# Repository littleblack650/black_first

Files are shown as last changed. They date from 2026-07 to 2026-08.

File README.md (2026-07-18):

# -
小鱼干 是一款全磁吸、模块化的开源桌宠机器人。它集成了语音识别、姿态感知、表情动画与舵机动作，支持二次开发，适合机器人爱好者、创客和学生入门嵌入式与机器人技术。/XiaoYuGan is an open‑source, fully magnetic modular desktop pet robot. It combines offline voice recognition, motion sensing, expressive animations, and servo movements, making it an ideal learning platform for embedded systems and robotics.

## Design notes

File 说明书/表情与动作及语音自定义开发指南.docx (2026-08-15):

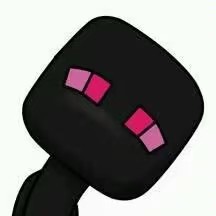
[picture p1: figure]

小鱼干桌宠机器人 · 表情与动作及语音

自定义开发指南

作者：生活中的小黑

本文档旨在说明如何为机器人新增一个表情（单帧或多帧动画），并为该表情编写对应的舵机动作序列，使其在表情播放时同步执行并自定义语音指令。

一、总体流程概览

阶段一：添加新表情

1. 定义表情类型（face.h 中增加枚举）
2. 生成并烧录图片（取模 → 上传到 Flash，记录地址）
3. 定义动画序列（face.c 中创建帧数组，单帧可跳过）
4. 配置表情参数（face.c 的配置表中注册表情）

→ 成果：OLED 能显示该表情

阶段二：编写舵机动作

1. 实现非阻塞动作函数（pwm.c 中用 ServoSequenceCommand 或 Servo_Set_NonBlocking 编写）
2. 在 system_manager.c 的 ExpressionWithServo 中绑定（表情出现时自动触发动作）

→ 成果：表情播放时舵机同步动作

阶段三：绑定语音指令

1. 定义指令编号（usart.h 枚举中添加）
2. 映射到表情（face.c 的 VoiceCommand_To_FaceType 中添加映射）
3. 配置语音模块（SU-03T 工具中新增词条，返回值与编号一致）
4. 执行业务逻辑（system_manager.c 的 VoiceCommandHandler 中添加处理）

→ 成果：说出口令机器人响应

阶段四：随机表情配置（可选）

在 random.c 的 default_probability_table 中添加概率条目

→ 成果：该表情会在空闲时随机自动出现

阶段五：测试验证

1. 单帧测试（用 W25Q64_ReadData 读取指定地址并显示）
2. 语音触发测试
3. 随机触发测试

→ 成果：功能稳定，可投入使用

二、详细步骤

为便于理解，将整个流程划分为四个独立阶段：

1. 添加新表情（准备图片→配置代码）
2. 关联动作（编写舵机动作→绑定到表情）
3. 绑定语音指令（定义指令→映射→处理）
4. 随机显示配置（设置概率表）

以下按阶段逐步说明，每个阶段只列出必须修改的文件和关键代码。

阶段一：添加新表情

1.1 定义表情类型（face.h）

在 FaceType 枚举中添加新成员，放在 FACE_COUNT 之前。

1.2 准备图片数据并烧录(具体操作可以搜索我的B站和抖音教程)

- 单帧：使用 image2cpp 在线工具将 128×64 图片转为数组。
- 多帧：使用“小黑的视频抽帧工具.exe”提取帧序列。
- 上传：使用“小黑的表情上传工具.exe”通过串口烧录到 W25Q64。
- 记录地址：工具会返回每帧的起始地址（如 0x000000、0x001000）。

接线图：USB转TTL模块与开发板连接方式如下。
模块TXD → 开发板RXD（PA10），模块RXD → 开发板TXD（PA9），共地。

1.3 定义动画序列（face.c，仅多帧）

创建 AnimationFrame 数组，填入地址和延时：

1.4 配置表情参数（face.c）

在 default_face_configs 中添加配置项，注意单帧与多帧的区别：

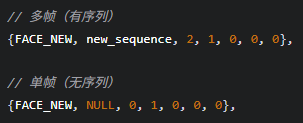
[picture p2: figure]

- sequence：序列指针（多帧填数组名，单帧填 NULL）
- sequence_length：帧数（单帧填 0）
- loop_count：循环次数（0 为无限循环）
- 最后两个 0 为预延迟（一般不用），has_special_behavior 通常为 0

1.5 （仅单帧）设置显示时长（face.c）

在 single_frame_times 中添加：

阶段二：关联动作

2.1 编写舵机动作函数（pwm.c）

必须非阻塞，推荐使用序列命令：

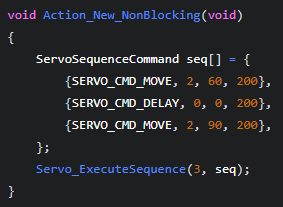
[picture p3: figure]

2.2 关联到表情（system_manager.c）

在 ExpressionWithServo 函数的 switch(currentFace) 中添加：

这样表情出现时自动执行对应动作。

提示：若动作需要由语音单独触发，还需在 VoiceCommandHandler 中添加（见阶段三）。

阶段三：绑定语音指令

3.1 定义指令编号（usart.h）

在 VoiceCommand 枚举中添加新值（推荐 0x30 起）：

3.2 映射到表情（face.c）

在 VoiceCommand_To_FaceType 中添加：

3.3 执行业务逻辑（system_manager.c）

在 VoiceCommandHandler 的 switch (face_type) 中添加：

或者，若动作与表情关联已在阶段二完成，则此处只需触发表情：

3.4 配置语音模块（SU-03T工具）

- 新增词条（如“新指令”），返回值设为 0x30（与3.1一致）。
- 生成固件并烧录到语音模块。

阶段四：随机显示配置

在 random.c 的 default_probability_table 中增加条目：

- 概率值总和不超过100。
- 间隔控制该表情连续出现的频率。

三、注意事项（摘要）

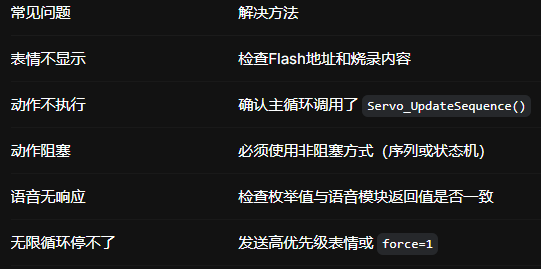
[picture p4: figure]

资源限制：g_sequence 数组大小为20（pwm.c中），若动作命令数超出，请修改数组大小或拆分执行。

通过以上四个阶段，您可以快速为“小鱼干”添加新表情、动作和语音指令，并实现随机展示。更多细节请参考视频教程（B站/抖音：生活中的小黑）。

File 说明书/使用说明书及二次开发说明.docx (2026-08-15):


小鱼干桌宠机器人

使用说明书 & 二次开发指南

感谢您选择“小鱼干”——一款全磁吸、模块化、可编程的智能桌宠机器人。本产品由作者独立开发并生产，所有电路均为模块化设计，无需自行焊接 PCB，方便维修与二次开发。请仔细阅读本手册，让您的小鱼干更快融入您的桌面生活。

一、产品概述

- 产品名称：小鱼干智能桌宠机器人
- 主控：STM32F103C8T6
- 存储器：W25Q64（8MB Flash，存储表情动画）
- 语音模块：SU-03T（支持离线语音指令）
- 姿态传感器：MPU6050（六轴，用于晃动、躺倒检测）
- 显示：1.3 寸 OLED（128×64，黑白）
- 舵机：MG90S ×2（控制头部点头、摇头）
- 电源管理：TP4056 充电 + DC-DC 5V 升压模块
- 触摸传感器：TTP223（电容式，位于头顶）
- 供电：3.7V 锂电池 + Type-C 充电底座

结构特点

- 全磁吸无螺丝设计：外壳采用 3D 打印，各部件通过磁吸固定，无需工具即可拆卸，方便维修与改装。
- 模块化电路：所有电子模块通过杜邦线或排针连接，无需定制 PCB，降低 DIY 门槛。
- 磁吸扩展接口：头部、手臂预留磁吸点，可更换装饰手套、头戴挂件（官方提供多种款式，也支持自制）。

二、包装清单

序号 | 名称 | 数量 | 备注
1 | 小鱼干机器人主体（含电池） | 1 | 默认装配完成
2 | 磁吸充电底座 | 1 | 含 Type-C 母座
3 | 磁吸手套（左右手） | 1 对 | 默认赠送“小鱼干”主题款
4 | 磁吸头戴装饰 | 1 个 | 默认小鱼鳍造型
5 | USB Type-C 数据线 | 1 | 充电/数据传输
6 | 使用说明书 & 二次开发指南 | 1 本 | 电子版见自媒体发布链接

额外装饰配件（如猫耳、蝴蝶结、节日限定款）请关注作者动态。

三、使用说明

3.1 首次使用

1. 充电：将充电底座的 Type-C 口连接到任意 5V USB 电源（手机充电器、电脑 USB、充电宝均可）。充电时底座指示灯亮红，充满转绿。
2. 放置机器人：将小鱼干的底部磁吸触点对准底座凹槽，轻轻放下，听到“咔哒”一声即吸附到位。
3. 开机：机器人左侧为电源开关，拨到“ON”位置，屏幕亮起，播放开机动画。
4. 语音唤醒：直接说出指令词（见附录），机器人会做出表情和动作。

提示：出厂时电池可能为虚电，建议先充电 1 小时再使用。

3.2 充电注意事项

- 边充边用：支持充电时正常使用，不影响语音、表情和舵机动作。
- 充电兼容性：任何 Type-C 手机充电器（5V/1A 及以上）、电脑 USB 口均可。不要求特定充电器。
- 充电状态指示：
  - 底座红灯常亮：充电中
  - 底座蓝灯常亮：充满或未放置机器人
  - 底座灯灭：电源未接通

3.3 电源开关与复位

位置 | 功能
左侧拨动开关 | ON：开机；OFF：关机
右侧 MicroUSB 接口 | SWD 烧录/调试口（供开发者使用）
复位方式 | 若屏幕显示异常，重启即可恢复。

3.4 语音指令映射表

指令编号 | 语音关键词 | 触发表情 | 动作
0x01 | 小鱼干 | RESPOND1 | 点头响应
0x02 | 你好 BT | BT | 无
0x03 | 揍你 | ANGRY1 | 摇头+拒绝
0x04 | 笑一个 | SMILE | 微笑+点头
0x05~0x0B | 音量调节 | RESPOND1 | 仅反馈（无动作）
0x0C | 唱首歌 | KEBISING | 唱歌动画+跳舞
0x0D | 我爱你 | LOVE | 爱心表情+四周看
0x0E | 往上看 | UP | 抬头
0x0F/0x11/0x12 | 狠一点/干他 | ANGRY2/3 | 摆头
0x13 | 哭一个 | CRY | 低头+哭泣动画
0x14 | 伤心 | SAD | 低头+悲伤动画
0x16 | 我帅吗 | DOUBT | 疑惑表情+歪头
0x17 | 吃饭 | EAT | 咀嚼动画+低头
0x18 | 呕吐 | VOMIT | 呕吐动画+挣扎
0x19 | 生气 | ANGRY | 常规生气
0x1A | 往下看 | DOWN | 低头
0x1B | 往左看 | LEFT | 左转头
0x1C | 往右看 | RIGHT | 右转头
0x1D | 给大家拜个年 | BAINIAN | 无
0x1E | 睡觉吧 | SLEEP | 睡眠动画+定格
0x1F | 起床啦 | WAKE | 唤醒动画+抬头
0x20 | 老大 | KEBI | 敬礼动作
0x21 | 老大我想你了 | KEBISING | 唱歌
0x22 | 立正 | RESPOND3 | 挺胸+严肃表情
0x23 | 放个烟花 | DANCE | 点头+烟花动画
0x24 | 曼波 | 无 | 无
0x25 | 真菜 | 无 | 无
0x26 | 真棒 | 无 | 无

3.5 语音及表情烧录引脚说明

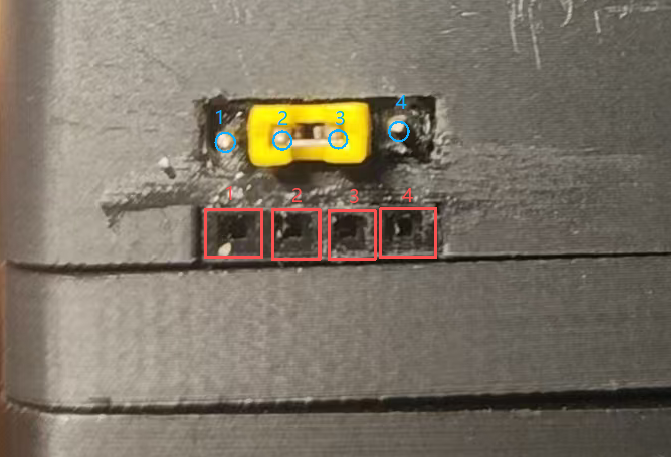
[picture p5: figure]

1. 连接上方4号引脚

2. 连接开发板5v引脚

3. 连接su-03t语音模块的5v引脚

4. 连接下方的1号接口，负责提供5v供电

1. 连接上方4号接口，负责提供5v供电

2. 连接su-03t语音模块的B7/TX引脚和开发板B7/RX引脚

3. 连接su-03t语音模块的B6/RX引脚和开发板B6/TX引脚

4. 连接su-03t语音模块的GND引脚和开发板GND引脚

3.6 语音及表情烧录操作方法

表情烧录：跳线帽连接1号和2号引脚（仅给开发板供电）

且TTL模块的Tx连接下方的2号引脚，Rx连接下方的3号引脚

语音烧录：跳线帽连接3号和4号引脚（仅给语音模块供电）

且TTL模块的Tx连接下方的3号引脚，Rx连接下方的2号引脚

烧录完成后：跳线帽连接2号和3号引脚（开发板给语音模块供电）

四、常见问题

Q：为什么内部走线看起来很乱？
A：为方便模块化更换和维修，所有模块均通过杜邦线连接，未定制 PCB。这可能对部分传感器产生轻微电磁干扰。在插电使用时（电量充足时）干扰最小，建议养成插电习惯。

Q：屏幕偶尔会乱码，怎么办？
A：断电重启即可。此问题通常由静电或电机启动时的大电流瞬时干扰引起，不影响长期可靠性。

Q：电池能续航多久？
A：满电连续使用约 1小时（视表情和动作频率），插电使用可以续航时间无限制。若长时间插电使用，建议偶尔断开电源让电池进行一次完整充放电，以延长寿命。

Q：能自己写新的表情和动作吗？
A：完全可以。我们提供完整的源码、取模工具、上传工具和教程，请参考“二次开发说明”章节。

Q：底座上的两侧触点怎么用？
A：它们是留给高级玩家连接移动底盘、扩展传感器等外部模块的。您可以制作带 MCU 的扩展底座，通过串口或 GPIO 与小鱼干主控通信。

五、支持与社区

- 技术文档与源码：访问作者GitHub仓库或关注作者抖音、哔哩哔哩等自媒体账号在相关视频简介中获取或粉丝交流群中获取
- 视频教程：抖音、哔哩哔哩搜索 “生活中的小黑”，观看表情制作、代码修改、外壳改装等系列视频。
- 问题反馈：可在视频评论区留言或私信，作者会尽量解答。
- 二次开发作品分享：欢迎在话题 #小鱼干改装 下晒出您的创意。

小鱼干桌宠机器人 —— 不仅是桌面萌物，更是您进入嵌入式与机器人世界的起点。
祝您玩得开心，改装出独一无二的小鱼干！

版本：V2.0
发布日期：2026 年 5月
作者：生活中的小黑

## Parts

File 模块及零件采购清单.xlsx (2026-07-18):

物料表
名称 | 数量
stm32f103c8t6最小系统开发板 | 1
st-link仿真器（烧录程序用） | 1
USB转TTL模块（烧录表情和语音用） | 1
su-03t语音模块 | 1
3.7v转5v迷你DC升压模块 | 1
6.3v2200uF电解电容10x12mm | 1
TP4056充电板 | 1
TTP223触摸模块 | 1
彩色排线 | 1
AMS1117-3.3v | 1
圆柱磁铁直径4mm厚度1.65mm | 100
6022P电容麦 | 1
SS12F15VG6拨动开关2档3脚 | 1
PogoPin弹簧针连接器触点1.5x3mm | 8
SMBJ5.0A TVS管 | 1
0402，0.1uF，104电容 | 1
MG90S铁齿180度舵机 | 2
502030，3.7v锂电池 | 1
1.25-2P端子4欧2W3525腔体扬声器 | 1
W25Q64 | 1
MPU6050 | 1
4P单排母直针 | 1
4P排针 | 1
跳线帽 | 1
1.3寸4脚蓝色OLED | 1
3D打印外壳 | 1

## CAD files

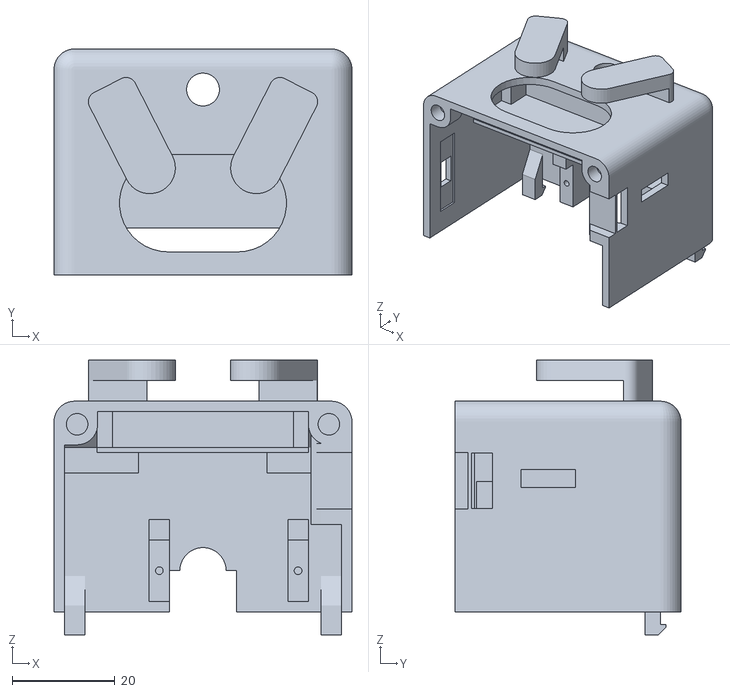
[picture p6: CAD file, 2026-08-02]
外壳打印文件/身体.STL
58.0 x 44.0 x 53.5

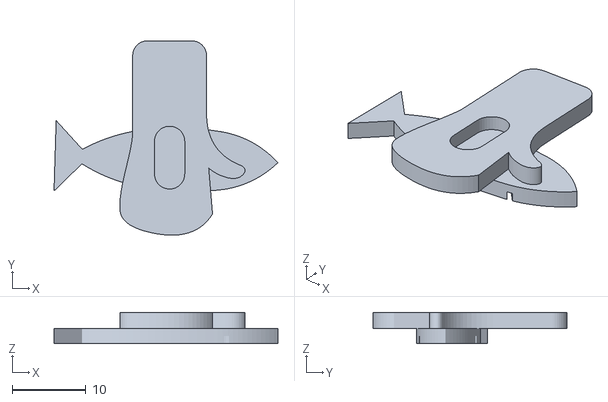
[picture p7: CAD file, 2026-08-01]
外壳打印文件/兔手套.STL
30.3 x 26.3 x 4.20

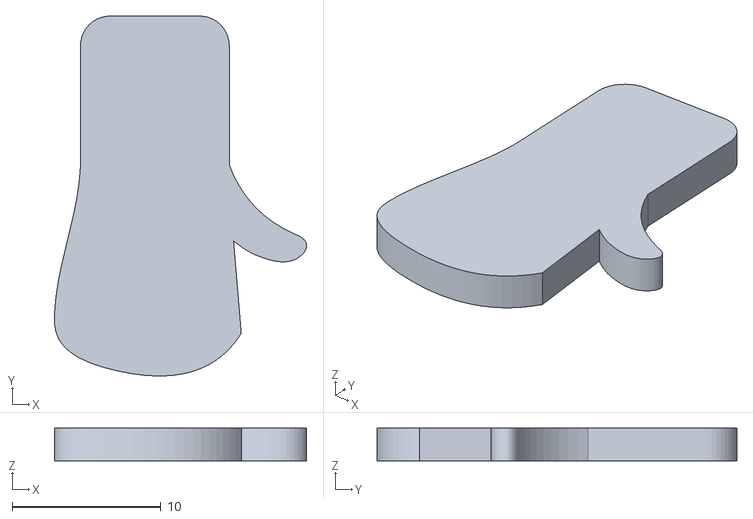
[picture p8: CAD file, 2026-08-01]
外壳打印文件/兔手套右.STL
16.9 x 24.2 x 2.20

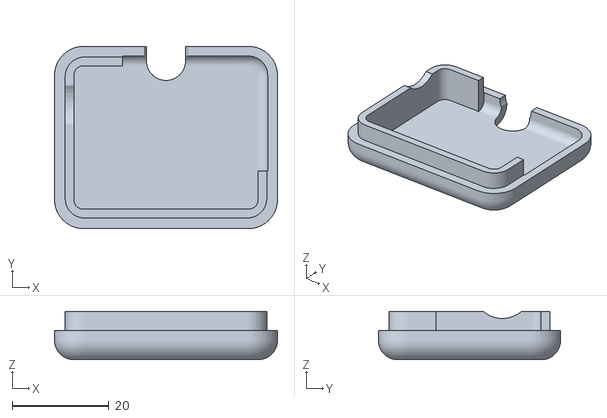
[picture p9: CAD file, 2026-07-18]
外壳打印文件/后脑勺0.2组装公差版本.STL
46.0 x 37.6 x 10.0

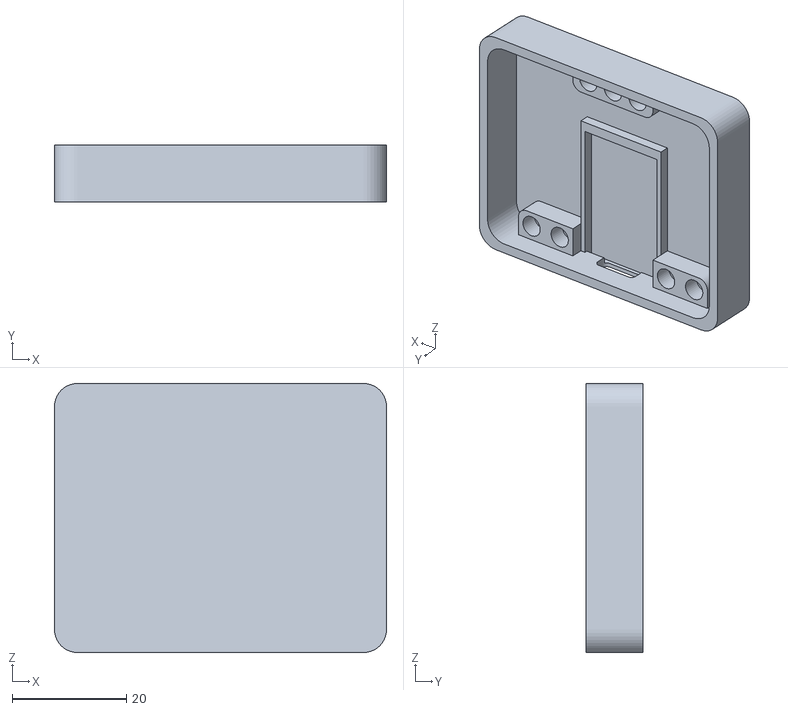
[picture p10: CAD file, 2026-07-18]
外壳打印文件/充电底座下盖.STL
58.0 x 10.0 x 47.0

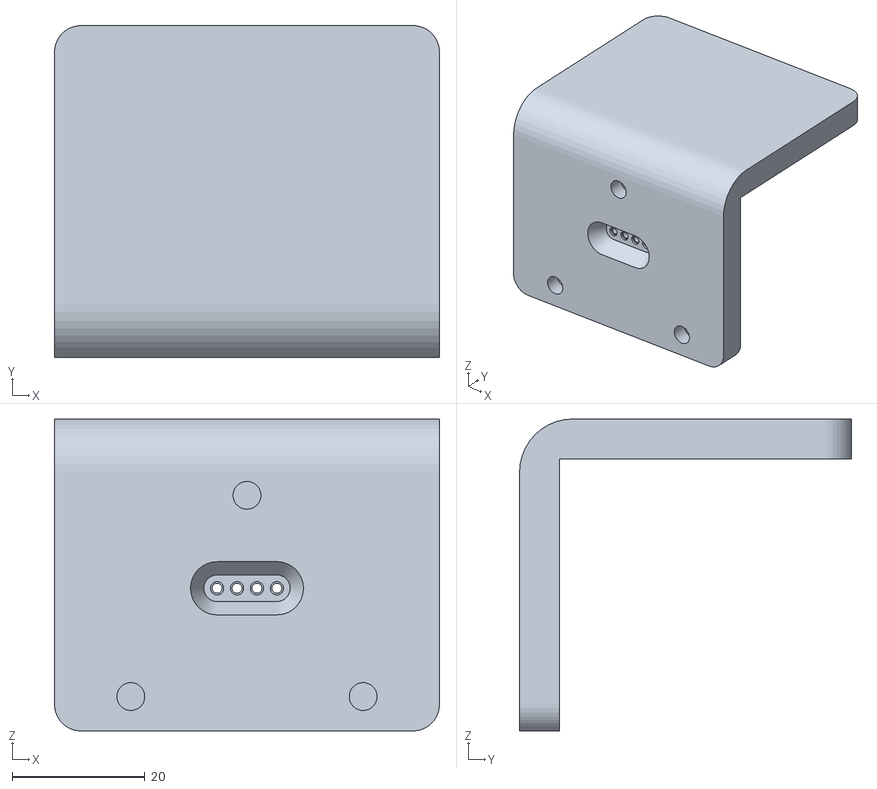
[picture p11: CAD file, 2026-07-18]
外壳打印文件/底盖.STL
58.0 x 50.0 x 47.0

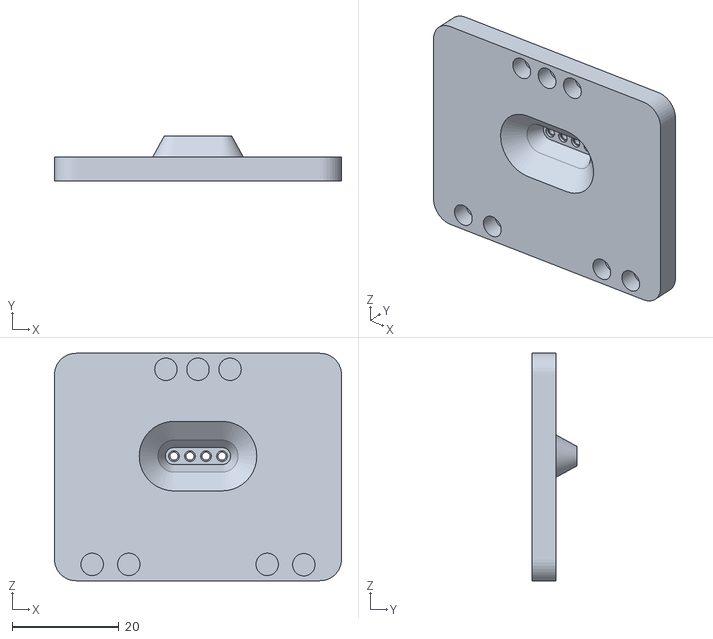
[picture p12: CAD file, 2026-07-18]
外壳打印文件/充电底座上盖.STL
53.7 x 8.50 x 42.6

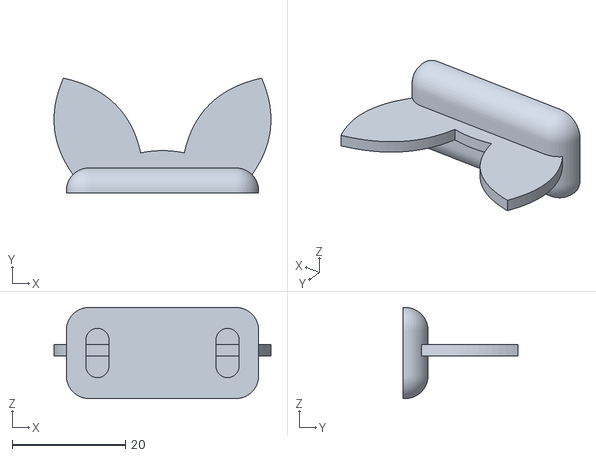
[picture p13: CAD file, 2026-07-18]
外壳打印文件/猫耳朵.STL
38.4 x 20.3 x 16.1

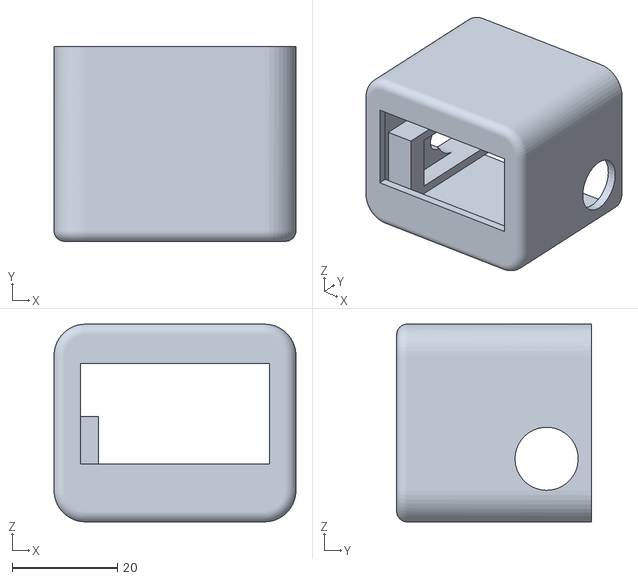
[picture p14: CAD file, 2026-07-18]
外壳打印文件/头部.STL
46.0 x 37.0 x 37.6

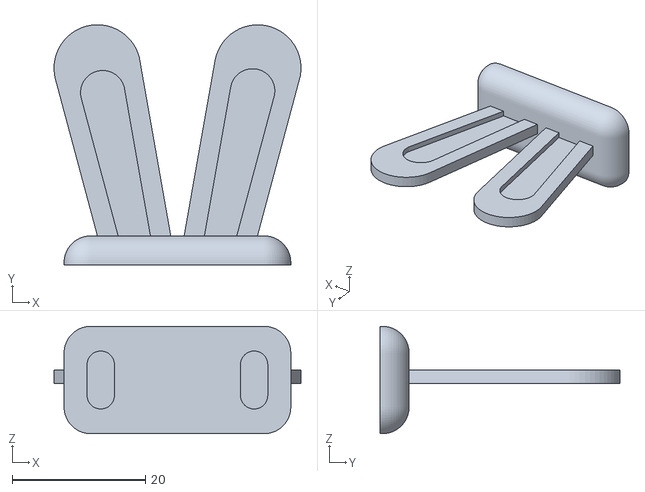
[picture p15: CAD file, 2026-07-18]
外壳打印文件/兔耳朵.STL
37.0 x 36.1 x 16.1

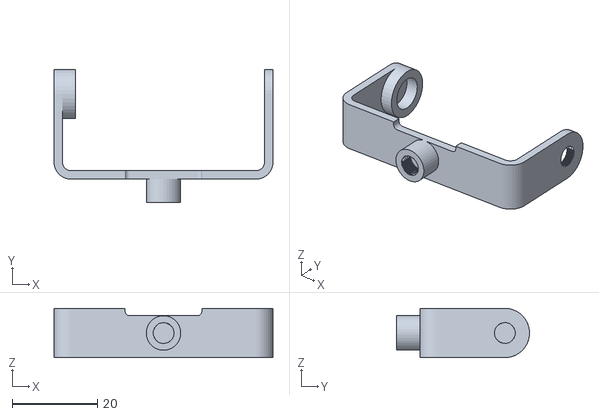
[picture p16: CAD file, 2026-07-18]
外壳打印文件/脖子.STL
51.5 x 31.3 x 11.6

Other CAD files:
外壳打印文件/后脑勺.STL

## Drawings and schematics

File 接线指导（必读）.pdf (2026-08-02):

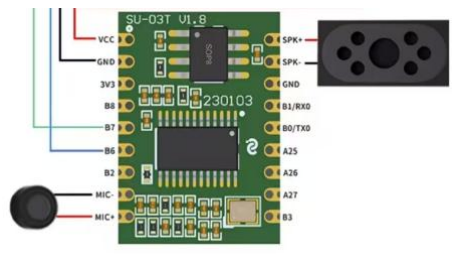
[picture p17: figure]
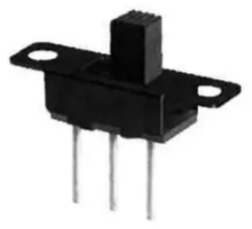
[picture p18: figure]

ttp223 触摸模块 | 4P 排针 | 4P 排母 | Su-03t 语音模块 | 两档三脚拨动开关 | 迷你升压模块

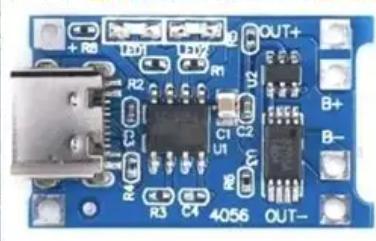
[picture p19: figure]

舵机 | W25Q64 存储模块 | mpu6050 模块 | 1.3 寸 OLED 模块 | Tp4056 充电模块

## AMS1117

## （给开发板芯片辅助供电）

## 电解电容

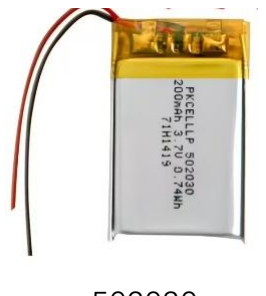
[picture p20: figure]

502030

### 3.7v 锂电

池

# 模块通识图

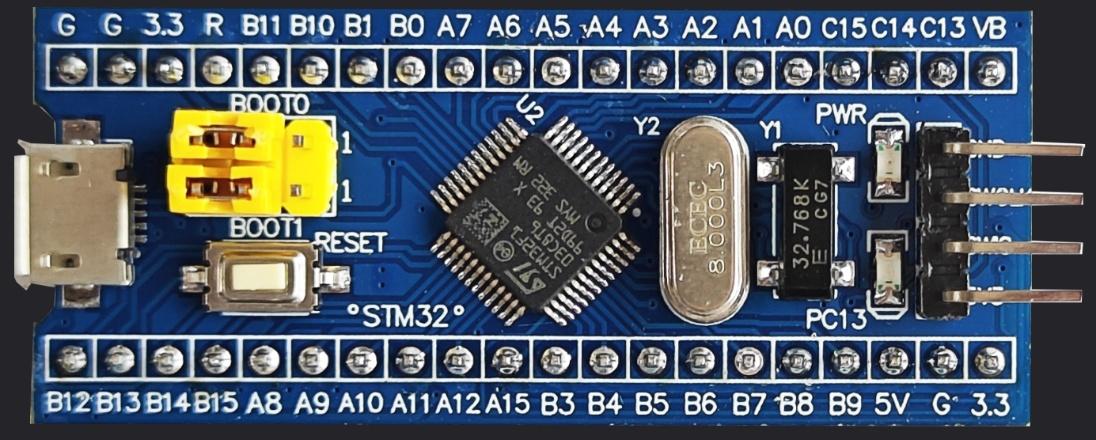
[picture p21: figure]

## STM32F103C8T6 最小系统开发板

## （整个机器人的大脑）

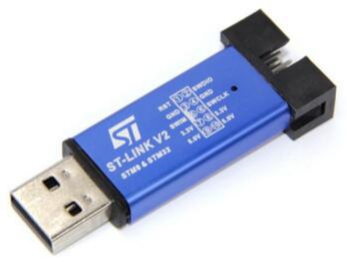
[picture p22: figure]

## st-link 仿真器（用于给芯片上传程序）

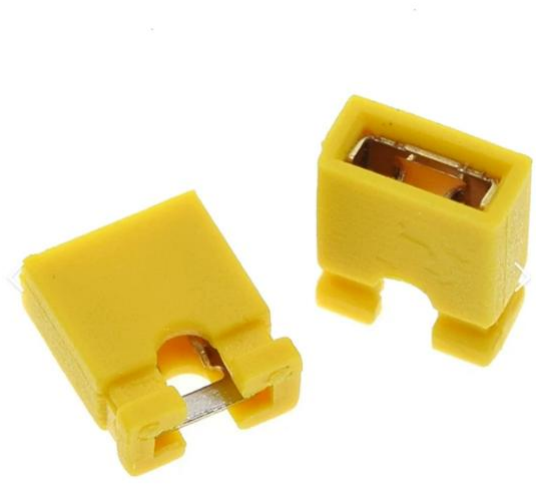
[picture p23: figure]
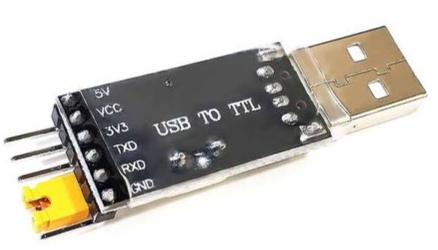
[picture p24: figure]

USB 转 TTL 模块（用于给机器人上传表情和语音） | 跳线帽（用于连接相邻的两个引脚）

# 注意：如果“5v” 前面没有特殊说

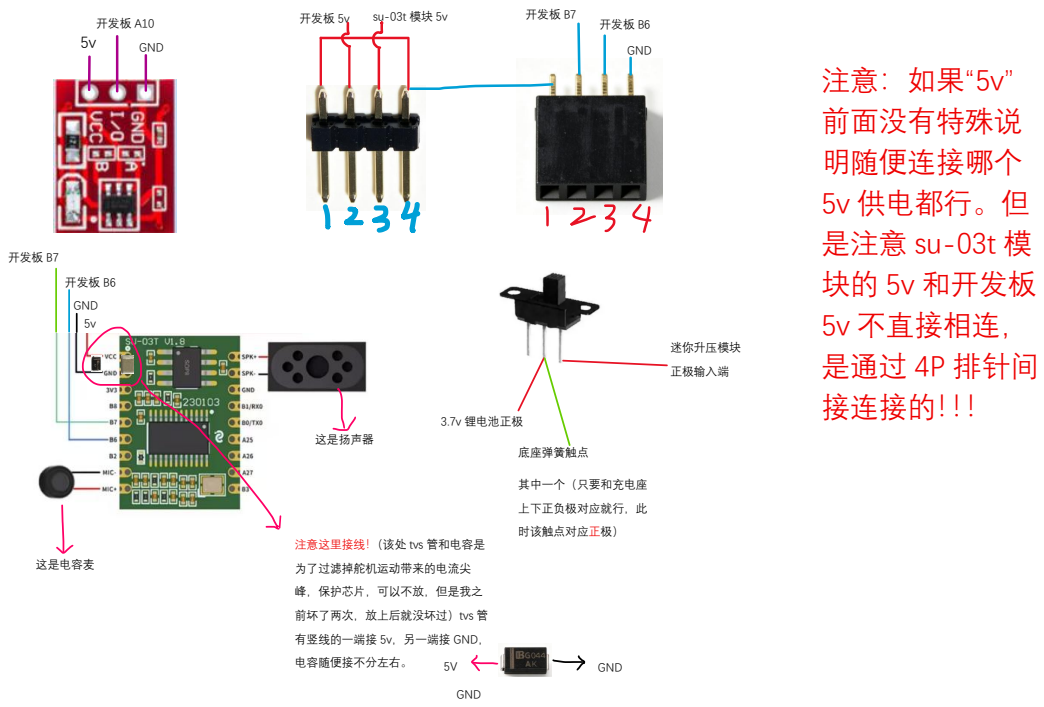
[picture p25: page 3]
开发板 5v; 开发板 B7; 开发板 B6 GND 5v; 开发板 A10; GND; 开发板 B6; GND 5v; 迷你升压模块; 正极输入端; 3.7v 锂电池正极; 底座弹簧触点; 其中一个（只要和充电座; 上下正负极对应就行，此; 时该触点对应正极）; 明随便连接哪个 5v 供电都行。但 是注意 su-03t 模 块的 5v 和开发板 5v 不直接相连， 是通过 4P 排针间 接连接的！！！; 这是电容麦; 这是扬声器; 电容随便接不分左右。

注意这里接线！（该处 tvs 管和电容是

为了过滤掉舵机运动带来的电流尖
峰，保护芯片，可以不放，但是我之

前坏了两次，放上后就没坏过）tvs 管
有竖线的一端接 5v，另一端接 GND，

5V

## 迷你升压模块使用指导 （注意：一定要按照指导严格操作，否则直接连接 12v 高压会击穿损坏芯片）

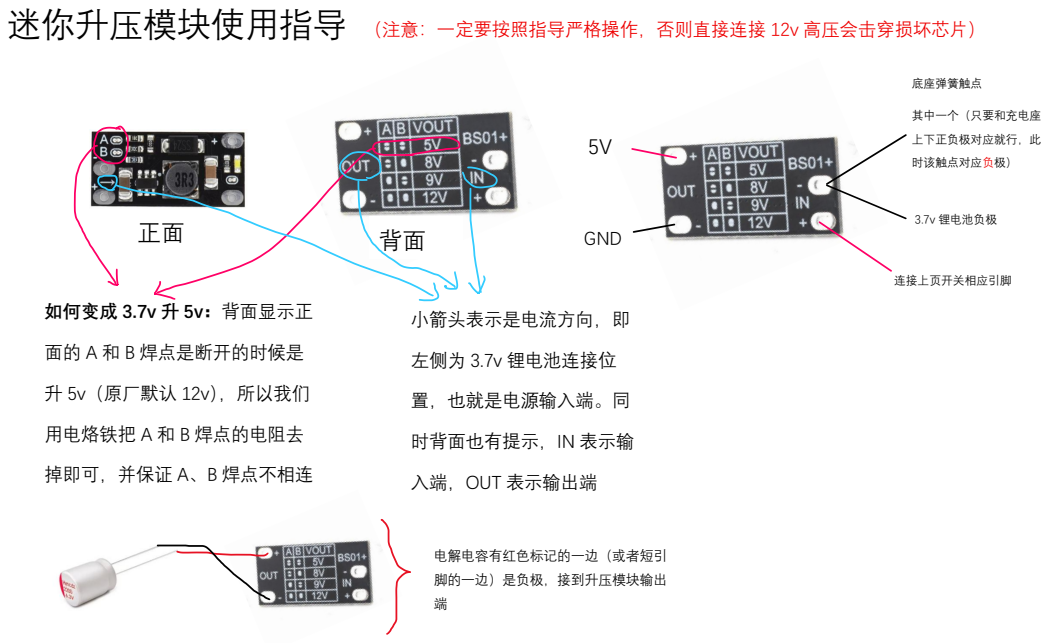
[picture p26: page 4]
如何变成 3.7v 升 5v：背面显示正; 面的 A 和 B 焊点是断开的时候是; 升 5v（原厂默认 12v），所以我们; 用电烙铁把 A 和 B 焊点的电阻去; 小箭头表示是电流方向，即; 左侧为 3.7v 锂电池连接位; 置，也就是电源输入端。同; GND; 连接上页开关相应引脚; 3.7v 锂电池负极; 底座弹簧触点; 其中一个（只要和充电座; 上下正负极对应就行，此; 时该触点对应负极）

时背面也有提示，IN 表示输

掉即可，并保证 A、B 焊点不相连

入端，OUT 表示输出端

电解电容有红色标记的一边（或者短引
脚的一边）是负极，接到升压模块输出

# - Tp4056 充电模块两个触点连接

# 两个底座触点，负责给电池充

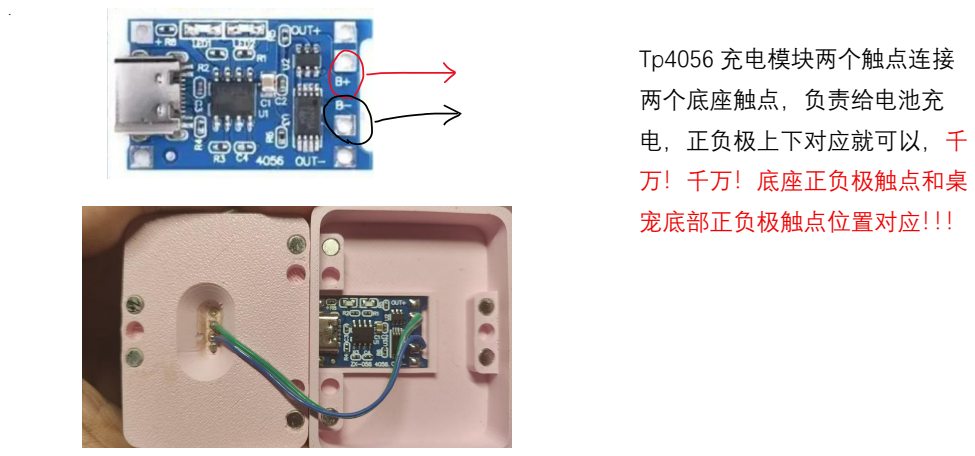
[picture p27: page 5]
电，正负极上下对应就可以，; 万！千万！底座正负极触点和桌; 宠底部正负极触点位置对应！！！

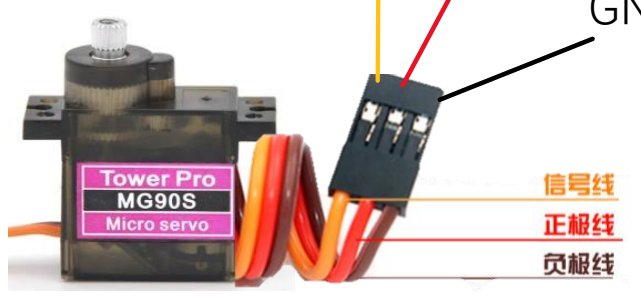
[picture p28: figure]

### 1 号舵机连开发板

A8，2 号连 A9
5v

## GND


5v

开发板 A15

开发板 B4

GND

开发板 B3

开发板 B5


5v GND

开发板 B10
开发板 B11

5v

GND

开发板 B8

开发板 B9

GND | 开发板 3.3v | 5v

·


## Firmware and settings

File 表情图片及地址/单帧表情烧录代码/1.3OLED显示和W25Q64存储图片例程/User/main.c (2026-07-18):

#include "stm32f10x.h"                  // Device header
#include "Delay.h"
#include "OLED.h"
#include "W25Q64.h"

u8 readBuffer1[1024] __attribute__((section(".ccmram"))); // 使用CCM RAM
//u8 readBuffer2[1024] __attribute__((section(".ccmram")));
u8 readBuffer1[1024]={// '4', 128x64px
// '8', 128x64px
0x00, 0x00, 0x00, 0x00, 0x00, 0x00, 0x00, 0x00, 0x00, 0x00, 0x00, 0x00, 0x00, 0x00, 0x00, 0x00, 
0x00, 0x00, 0xf0, 0xf8, 0xf8, 0xf8, 0xf0, 0xf0, 0xf0, 0xe0, 0xe0, 0xc0, 0xc0, 0xc0, 0x80, 0x80, 
0x80, 0x00, 0x00, 0x00, 0x00, 0x00, 0x00, 0x00, 0x00, 0x00, 0x00, 0x00, 0x00, 0x00, 0x00, 0x00, 
0x00, 0x00, 0x00, 0x00, 0x00, 0x00, 0x00, 0x00, 0x00, 0x00, 0x00, 0x00, 0x00, 0x00, 0x00, 0x00, 
0x00, 0x00, 0x00, 0x00, 0x00, 0x00, 0x00, 0x00, 0x00, 0x00, 0x00, 0x00, 0x00, 0x00, 0x00, 0x00, 
0x00, 0x00, 0x00, 0x00, 0x00, 0x00, 0x00, 0x00, 0x00, 0x00, 0x00, 0x00, 0x00, 0x00, 0x00, 0x00, 
0x00, 0x80, 0x80, 0xc0, 0xc0, 0xc0, 0xe0, 0xe0, 0xf0, 0xf0, 0xf8, 0xf8, 0xf8, 0xfc, 0xfc, 0xfe, 
0xfe, 0xfe, 0xfc, 0xf8, 0x00, 0x00, 0x00, 0x00, 0x00, 0x00, 0x00, 0x00, 0x00, 0x00, 0x00, 0x00, 
0x00, 0x00, 0x00, 0x00, 0x00, 0x00, 0x00, 0x00, 0x00, 0x00, 0x00, 0x00, 0x00, 0x00, 0x00, 0x00, 
0x00, 0x00, 0xff, 0xff, 0xff, 0xff, 0xff, 0xff, 0xff, 0xff, 0xff, 0xff, 0xff, 0xff, 0xff, 0xff, 
0xff, 0xff, 0xff, 0xfe, 0xfe, 0xfe, 0xfc, 0xfc, 0xf8, 0xf8, 0xf8, 0xf0, 0xf0, 0xf0, 0xe0, 0xe0, 
0xc0, 0xc0, 0xc0, 0x80, 0x80, 0x00, 0x00, 0x00, 0x00, 0x00, 0x00, 0x00, 0x00, 0x00, 0x00, 0x00, 
0x00, 0x00, 0x00, 0x00, 0x00, 0x00, 0x00, 0x00, 0x00, 0x00, 0x00, 0x00, 0x00, 0x00, 0x80, 0x80, 
0xc0, 0xc0, 0xc0, 0xe0, 0xe0, 0xf0, 0xf0, 0xf8, 0xf8, 0xf8, 0xfc, 0xfc, 0xfe, 0xfe, 0xfe, 0xff, 
0xff, 0xff, 0xff, 0xff, 0xff, 0xff, 0xff, 0xff, 0xff, 0xff, 0xff, 0xff, 0xff, 0xff, 0xff, 0xff, 
0xff, 0xff, 0xff, 0xff, 0x00, 0x00, 0x00, 0x00, 0x00, 0x00, 0x00, 0x00, 0x00, 0x00, 0x00, 0x00, 
0x00, 0x00, 0x00, 0x00, 0x00, 0x00, 0x00, 0x00, 0x00, 0x00, 0x00, 0x00, 0x00, 0x00, 0x00, 0x00, 
0x00, 0x00, 0xff, 0xff, 0xff, 0xff, 0xff, 0xff, 0xff, 0xff, 0xff, 0xff, 0xff, 0xff, 0xff, 0xff, 
0xff, 0xff, 0xff, 0xff, 0xff, 0xff, 0xff, 0xff, 0xff, 0xff, 0xff, 0xff, 0xff, 0xff, 0xff, 0xff, 
0xff, 0xff, 0xff, 0xff, 0xff, 0xff, 0xff, 0xff, 0xfe, 0xfe, 0xfe, 0xfc, 0xfc, 0xf8, 0x00, 0x00, 
0x00, 0x00, 0x00, 0x00, 0x00, 0x00, 0xfc, 0xfe, 0xfe, 0xfe, 0xfe, 0xfe, 0xff, 0xff, 0xff, 0xff, 
0xff, 0xff, 0xff, 0xff, 0xff, 0xff, 0xff, 0xff, 0xff, 0xff, 0xff, 0xff, 0xff, 0xff, 0xff, 0xff, 
0xff, 0xff, 0xff, 0xff, 0xff, 0xff, 0xff, 0xff, 0xff, 0xff, 0xff, 0xff, 0xff, 0xff, 0xff, 0xff, 
0xff, 0xff, 0xff, 0xff, 0x00, 0x00, 0x00, 0x00, 0x00, 0x00, 0x00, 0x00, 0x00, 0x00, 0x00, 0x00, 
0x00, 0x00, 0x00, 0x00, 0x00, 0x00, 0x00, 0x00, 0x00, 0x00, 0x00, 0x00, 0x00, 0x00, 0x00, 0x00, 
0x00, 0x00, 0xff, 0xff, 0xff, 0xff, 0xff, 0xff, 0xff, 0xff, 0xff, 0xff, 0xff, 0xff, 0xff, 0xff, 
0xff, 0xff, 0xff, 0xff, 0xff, 0xff, 0xff, 0xff, 0xff, 0xff, 0xff, 0xff, 0xff, 0xff, 0xff, 0xff, 
0xff, 0xff, 0xff, 0xff, 0xff, 0xff, 0xff, 0xff, 0xff, 0xff, 0xff, 0xff, 0xff, 0xff, 0x00, 0x00, 
0x00, 0x00, 0x00, 0x00, 0x00, 0x00, 0xff, 0xff, 0xff, 0xff, 0xff, 0xff, 0xff, 0xff, 0xff, 0xff, 
0xff, 0xff, 0xff, 0xff, 0xff, 0xff, 0xff, 0xff, 0xff, 0xff, 0xff, 0xff, 0xff, 0xff, 0xff, 0xff, 
0xff, 0xff, 0xff, 0xff, 0xff, 0xff, 0xff, 0xff, 0xff, 0xff, 0xff, 0xff, 0xff, 0xff, 0xff, 0xff, 
0xff, 0xff, 0xff, 0xff, 0x00, 0x00, 0x00, 0x00, 0x00, 0x00, 0x00, 0x00, 0x00, 0x00, 0x00, 0x00, 
0x00, 0x00, 0x00, 0x00, 0x00, 0x00, 0x00, 0x00, 0x00, 0x00, 0x00, 0x00, 0x00, 0x00, 0x00, 0x00, 
0x00, 0x00, 0x01, 0x03, 0x03, 0x03, 0x03, 0x03, 0x03, 0x03, 0x03, 0x03, 0x03, 0x03, 0x03, 0x03, 
0x03, 0x03, 0x03, 0x03, 0x03, 0x03, 0x03, 0x03, 0x03, 0x01, 0x01, 0x01, 0x01, 0x01, 0x01, 0x81, 
0x81, 0x81, 0xc1, 0x41, 0x41, 0x41, 0x41, 0xc1, 0xc1, 0xc1, 0xc1, 0xc1, 0x81, 0x80, 0x00, 0x00, 
0x00, 0x00, 0x00, 0x00, 0x00, 0x00, 0x00, 0x01, 0x01, 0x01, 0x01, 0x81, 0x81, 0xc1, 0x41, 0x41, 
0x41, 0xc1, 0x61, 0x23, 0x23, 0x23, 0x33, 0x13, 0x13, 0xf3, 0xe3, 0xe3, 0xe3, 0xc3, 0xc3, 0x83, 
0x03, 0x03, 0x03, 0x03, 0x03, 0x03, 0x03, 0x07, 0x07, 0x07, 0x07, 0x07, 0x07, 0x07, 0x07, 0x07, 
0x07, 0x07, 0x07, 0x03, 0x00, 0x00, 0x00, 0x00, 0x00, 0x00, 0x00, 0x00, 0x00, 0x00, 0x00, 0x00, 
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
};

int main(void)
{
	OLED_Init();
	OLED_Clear();
	SystemInit();
	W25Q64_Init(); 
    // 写入1024字节图片数据到地址0x10000
//    W25Q64_WriteData(0x0B2000, readBuffer1, sizeof(readBuffer1));
//		W25Q64_EraseSector(0x045000);
//	Delay_ms(100);
    W25Q64_ReadData(0x0B3000, readBuffer1, sizeof(readBuffer1)); // 从地址 0x000400 读取图片
//    W25Q64_ReadData(0x001000, readBuffer2, sizeof(readBuffer2)); // 从地址 0x001000 读取图片
						//清屏
// 	OLED_ShowChar(1,1,'A',16,1);
//   	OLED_ShowString(16,1,"HelloWorld",16,1);
	
	while (1)
	{
	OLED_ShowPicture(0,0,128,64,readBuffer1,1);
	Delay_ms(100);
//	OLED_ShowPicture(0,0,128,64,readBuffer2,1);
//	Delay_ms(100);
	}
}

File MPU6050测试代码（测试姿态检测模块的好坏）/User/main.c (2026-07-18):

#include "stm32f10x.h"
#include "oled.h"           // 包含 oled.h 即可，无需 oledfont.h
#include "mpu6050.h"
#include <stdio.h>
#include <string.h>

// 简单的延时（不依赖 SysTick）
static void delay_us(uint32_t us)
{
    uint32_t i;
    for (; us > 0; us--)
    {
        i = 10;
        while (i--);
    }
}
static void delay_ms(uint32_t ms)
{
    while (ms--) delay_us(1000);
}

// LED 初始化（PC13 低电平点亮）
static void LED_Init(void)
{
    GPIO_InitTypeDef gpio;
    RCC_APB2PeriphClockCmd(RCC_APB2Periph_GPIOC, ENABLE);
    gpio.GPIO_Pin = GPIO_Pin_13;
    gpio.GPIO_Mode = GPIO_Mode_Out_PP;
    gpio.GPIO_Speed = GPIO_Speed_50MHz;
    GPIO_Init(GPIOC, &gpio);
    GPIO_SetBits(GPIOC, GPIO_Pin_13);
}
static void LED_On(void)  { GPIO_ResetBits(GPIOC, GPIO_Pin_13); }
static void LED_Off(void) { GPIO_SetBits(GPIOC, GPIO_Pin_13); }

int main(void)
{
    LED_Init();
    OLED_Init();
    delay_ms(100);

    // 针对 1.3 寸 OLED (SH1106) 的偏移修正（如果需要）
    // OLED_WR_Byte(0x02, OLED_CMD);  // 默认列起始地址，可尝试 0x00

    // 初始化 MPU6050 (PB8/PB9)
    SI2C_TypeDef mpu_i2c;
    mpu_i2c.SCL_GPIOx = GPIOB;
    mpu_i2c.SCL_GPIO_Pin = GPIO_Pin_8;
    mpu_i2c.SDA_GPIOx = GPIOB;
    mpu_i2c.SDA_GPIO_Pin = GPIO_Pin_9;
    MPU6050_Init(&mpu_i2c);
    delay_ms(100);

    // LED 闪烁 3 次表示启动成功
    for (int i = 0; i < 3; i++)
    {
        LED_On();
        delay_ms(200);
        LED_Off();
        delay_ms(200);
    }

    // 清屏并绘制固定标签（一次性）
    OLED_Clear();
    DrawStringToGRAM(0, 0, (u8*)"AccX:", 16, 1);
    DrawStringToGRAM(0, 16, (u8*)"AccY:", 16, 1);
    DrawStringToGRAM(0, 32, (u8*)"Pitch:", 16, 1);
    DrawStringToGRAM(0, 48, (u8*)"Roll:", 16, 1);
    OLED_Refresh();

    MPU6050_Data data;
    char line[20];

    while (1)
    {
        MPU6050_ReadData(&data);

        // 清除旧数值（12个空格足够）
        DrawStringToGRAM(50, 0, (u8*)"            ", 16, 1);
        DrawStringToGRAM(50, 16, (u8*)"            ", 16, 1);
        DrawStringToGRAM(50, 32, (u8*)"            ", 16, 1);
        DrawStringToGRAM(50, 48, (u8*)"            ", 16, 1);

        // 写入新数值
        snprintf(line, sizeof(line), "% 5.2f g", data.Accel_X);
        DrawStringToGRAM(50, 0, (u8*)line, 16, 1);
        snprintf(line, sizeof(line), "% 5.2f g", data.Accel_Y);
        DrawStringToGRAM(50, 16, (u8*)line, 16, 1);
        snprintf(line, sizeof(line), "% 6.1f deg", data.Angle_X);
        DrawStringToGRAM(50, 32, (u8*)line, 16, 1);
        snprintf(line, sizeof(line), "% 6.1f deg", data.Angle_Y);
        DrawStringToGRAM(50, 48, (u8*)line, 16, 1);

        // 一次性刷新整个屏幕
        OLED_Refresh();

        // LED 慢闪指示
        static uint32_t cnt = 0;
        if (++cnt >= 5)
        {
            cnt = 0;
            static uint8_t led_state = 0;
            if (led_state) LED_Off();
            else LED_On();
            led_state = !led_state;
        }

        delay_ms(200);
    }
}

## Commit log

2026-08-01 更新完善了接线教程并优化了部分打印文件
    [兔手套.STL, 兔手套右.STL, 身体.STL]
2026-08-02 更新接线教程
2026-08-02 更新身体3D打印外壳文件
    [身体.STL]
2026-08-02 更新引脚说明
2026-08-03 更新了主代码并修复了bug
2026-08-06 说明书更新
2026-08-12 日常更新
2026-08-15 实时更新
